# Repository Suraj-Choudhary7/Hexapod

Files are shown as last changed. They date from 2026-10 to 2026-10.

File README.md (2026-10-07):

# Hexapod Robot — ROS 2 / Gazebo Fortress

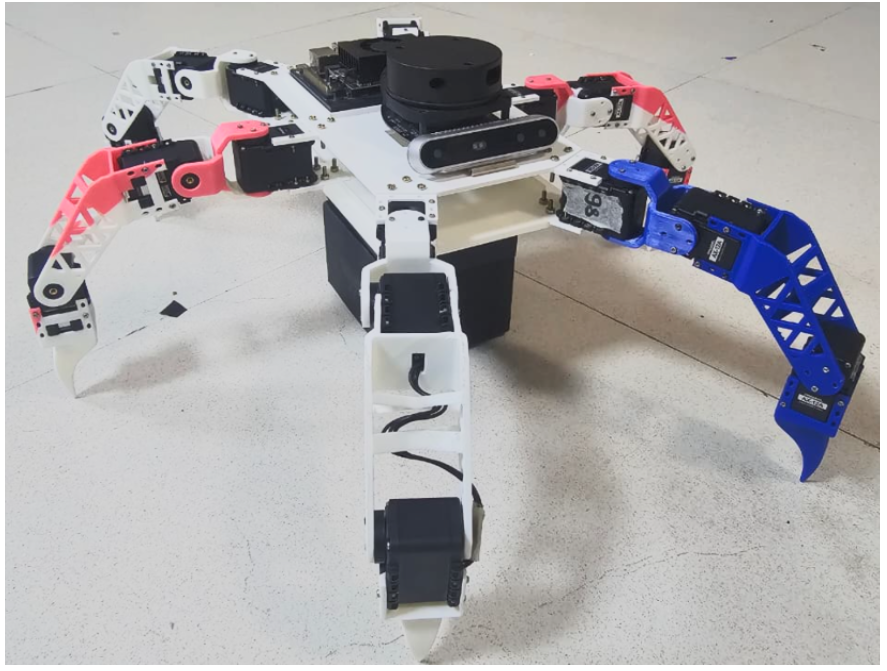
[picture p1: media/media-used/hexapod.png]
HexaPod


A 6-legged (hexapod) robot built from scratch: custom 3D-printed links, Dynamixel AX-series servos, a hand-derived URDF, and a fully original CPG-based walking controller written in Python on ROS 2 Humble.

<!-- Add a photo or GIF of the robot here -->
<!-- ![Robot photo](docs/images/robot.jpg) -->

---

## Table of Contents

- [What I Built & Learned](#what-i-built--learned)
- [Repository Structure](#repository-structure)
- [System Architecture](#system-architecture)
- [Package Details](#package-details)
  - [hexa\_control](#hexa_control)
  - [root\_description](#root_description)
- [Robot Specifications](#robot-specifications)
- [Getting Started](#getting-started)
  - [Prerequisites](#prerequisites)
  - [Build](#build)
  - [Run in Simulation (Gazebo Fortress)](#run-in-simulation-gazebo-fortress)
  - [Run on Hardware](#run-on-hardware)
  - [URDF Viewer (RViz only)](#urdf-viewer-rviz-only)
- [Controlling the Robot](#controlling-the-robot)
- [Screenshots & Videos](#screenshots--videos)
- [Roadmap](#roadmap)

---

## What I Built & Learned

This project started from zero — no existing codebase, no pre-made libraries for the walking controller. Here is what I worked through end-to-end:

**Mechanical & URDF**
- Designed 6 identical leg assemblies, each with 3 revolute joints (coxa → femur → tibia), and assembled them symmetrically around a hexagonal base body.
- Wrote the entire URDF by hand as a modular xacro file, including inertial tensors, STL mesh references (scaled from mm to m), and ros2\_control hardware interfaces.
- Tuned joint limits to ±120° (2.094 rad), damping, and friction to match the physical Dynamixel AX behaviour.

**3-DOF Inverse & Forward Kinematics**
- Derived the analytical IK for the leg: coxa rotation (θ₁) from `atan2(y, x)`, then a 2-link planar IK in the vertical plane for femur (θ₂) and tibia (θ₃) using the law of cosines.
- Implemented zero-angle compensation (`femur_zero_angle = -35°`, `tibia_zero_angle = -60°`) to map from geometric angles to servo-relative angles.
- Also implemented forward kinematics for verification.

**CPG Gait Generator**
- Implemented a **Central Pattern Generator (CPG)** based on **Hopf oscillators** — the same class of bio-inspired controllers used in real legged-robot research.
- Each leg has its own oscillator; a **phase-bias coupling matrix** locks Tripod A (`FH_LH`, `MH_RH`, `BH_LH`) and Tripod B (`FH_RH`, `MH_LH`, `BH_RH`) 180° out of phase, producing a stable tripod gait automatically.
- The system of ODEs is integrated at 50 Hz using **4th-order Runge-Kutta (RK4)** for numerical stability.
- Stance and swing phases use separate angular velocities (controlled by `duty_factor = 0.70`) so stance is slower and swing is faster, like a real walking leg.
- Foot trajectories blend a planar ground-contact sweep with a raised swing arc, and the swing height is shaped by `sin^0.8` for a smooth, rounded step.

**ROS 2 Control Node**
- Built a full ROS 2 lifecycle-style node (`hexa_node`) with a clean **state machine**: `RESTING → TRANSITIONING → WALKING → TRANSITIONING → RESTING`.
- The robot auto-stands when a `/cmd_vel` command arrives, walks while commands are active, and gracefully returns to a folded rest pose after 5 s of idling.
- All state transitions interpolate joint angles smoothly over a configurable `transition_duration` so nothing snaps or jerks.
- On `Ctrl+C` / shutdown, `destroy_node()` drives the robot back to rest synchronously before closing, protecting the hardware.

**Dynamixel Hardware Driver**

- Wrote a low-level ROS 2 node that subscribes to the same `JointTrajectory` topic and drives 18 Dynamixel AX servos via **GroupSyncWrite** — one USB packet per control cycle instead of 18 individual writes, keeping latency low.
- Implemented the angle → raw-value conversion with per-joint direction and zero-offset correction so the same IK angles work identically on both hardware and simulation.

**Simulation Bridge**
- Because Gazebo joint directions differ from physical servo directions, I wrote a lightweight `sim_relay` node that intercepts the trajectory, applies per-joint direction and offset corrections, and republis`hes — keeping `hexa_node` hardware-agnostic.

**Gazebo Fortress Integration**
- Integrated `gz_ros2_control` so the simulated robot is driven by the same `JointTrajectoryController` as the real one.
- Set up `ros_gz_bridge` for `/clock`, `/tf`, and `/odom` bridging.
- Tuned the controller YAML for **open-loop mode** — necessary because `hexa_node` streams 1-point trajectories at 50 Hz and closed-loop would keep aborting goals mid-execution.

---

## Repository Structure

```
Hexapod/
├── hexa_control/          # ROS 2 Python package — walking controller + hardware driver
│   ├── hexa_control/
│   │   ├── hexa_node.py            # Main control node (CPG + IK + state machine)
│   │   ├── gait.py                 # CPG Hopf oscillator gait generator
│   │   ├── kinematics.py           # Analytical 3-DOF IK / FK
│   │   ├── dynamixels_controller.py# Dynamixel AX hardware driver node
│   │   └── sim_relay.py            # Simulation direction-correction bridge
│   ├── setup.py
│   └── package.xml
│
└── root_description/      # ROS 2 CMake package — URDF, meshes, launch, config
    ├── urdf/
    │   ├── root.xacro              # Main robot URDF (all links & joints)
    │   ├── root.ros2_control.xacro # ros2_control hardware interface
    │   ├── root.gazebo.xacro       # Gazebo-specific plugins
    │   └── materials.xacro         # Visual materials
    ├── meshes/                     # STL files for all robot links
    ├── launch/
    │   ├── gz_sim.launch.py        # Full Gazebo Fortress + controller + hexa_node
    │   └── display.launch.py       # RViz + joint_state_publisher_gui (no sim)
    ├── config/
    │   └── controllers.yaml        # ros2_control controller config (100 Hz)
    ├── worlds/
    │   └── hexapod_world.sdf       # Custom Gazebo world
    └── rviz/
        └── root.rviz               # RViz configuration
```

---

## System Architecture

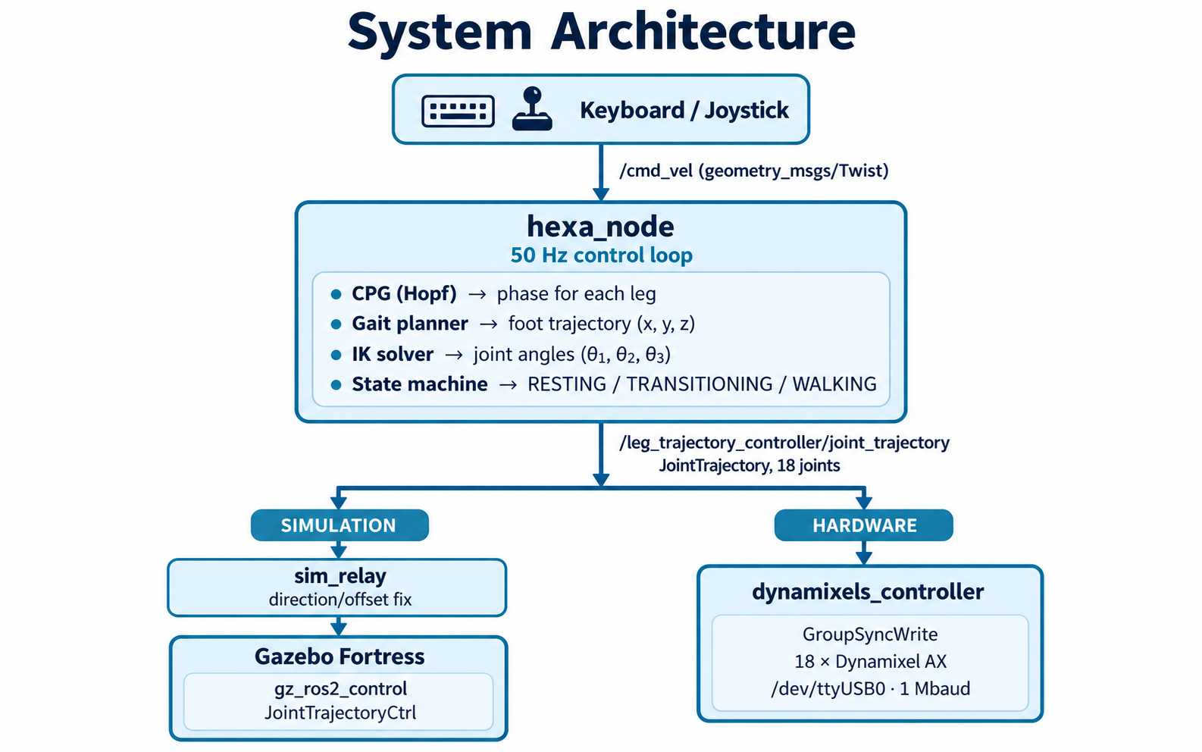
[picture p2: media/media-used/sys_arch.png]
System Architecture


---

## Package Details

### hexa_control

| File | Purpose |
|---|---|
| `hexa_node.py` | Main ROS 2 node. 50 Hz timer, state machine, integrates CPG + IK, publishes `JointTrajectory`. |
| `gait.py` | `CpgGait` class. Hopf oscillator per leg, RK4 integration, tripod phase coupling, foot trajectory. |
| `kinematics.py` | `Kinematics` class. Analytical IK (`theta1`, `theta2`, `theta3`) and FK. |
| `dynamixels_controller.py` | `DynamixelDriverNode`. Subscribes to `JointTrajectory`, converts angles to raw Dynamixel positions, SyncWrite at 1 Mbaud. |
| `sim_relay.py` | `SimRelayNode`. Translates `hexa_node` output to simulator joint conventions (direction flip + offsets). |

**ROS 2 entry points (from `setup.py`):**

```
hexa_node          → hexa_control.hexa_node:main
dynamixels_driver  → hexa_control.dynamixels_controller:main
sim_relay          → hexa_control.sim_relay:main
```

**Key parameters (hexa_node):**

| Parameter | Default | Description |
|---|---|---|
| `control_rate_hz` | `50.0` | Control loop frequency |
| `gait_frequency` | `0.5` | CPG oscillation frequency (Hz) |
| `step_height` | `0.06` | Swing phase foot lift (m) |
| `stance_reach_x` | `0.160` | Default foot forward reach (m) |
| `standing_height` | `-0.190` | Body height above ground (m) |
| `transition_duration_sec` | `1.5` | Sit/stand interpolation time (s) |
| `idle_to_rest_sec` | `5.0` | Idle timeout before sitting (s) |

---

### root_description

| File/Dir | Purpose |
|---|---|
| `urdf/root.xacro` | Full robot URDF: `base_link`, 6 Dynamixel mounts, 6 × 3 leg links, all joints |
| `urdf/root.ros2_control.xacro` | Hardware interface declaration for `gz_ros2_control` |
| `urdf/root.gazebo.xacro` | Gazebo Fortress plugin (`gz_ros2_control`) |
| `config/controllers.yaml` | `JointTrajectoryController` for 18 joints, 100 Hz, open-loop |
| `launch/gz_sim.launch.py` | Full sim launch: Gazebo + RSP + spawn + bridge + controllers + hexa_node + sim_relay |
| `launch/display.launch.py` | URDF viewer: RSP + joint_state_publisher_gui + RViz |
| `meshes/` | STL meshes for base, Dynamixel brackets, femur, tibia links |
| `worlds/hexapod_world.sdf` | Flat-ground Gazebo world |

---

## Robot Specifications

| Property | Value |
|---|---|
| Legs | 6 (hexapod) |
| DOF per leg | 3 (coxa, femur, tibia) |
| Total joints | 18 |
| Actuators | Dynamixel AX series (protocol 1.0) |
| Coxa length (l1) | 51 mm |
| Femur length (l2) | 110 mm |
| Tibia length (l3) | 148 mm |
| Body mass (URDF) | ~0.90 kg |
| Gait type | Tripod (CPG Hopf oscillator) |
| Control frequency | 50 Hz |
| Communication | USB-to-TTL @ 1 Mbaud |

**Leg naming convention:**

```
FH = Front Hex   MH = Middle Hex   BH = Back Hex
LH = Left Half   RH = Right Half

      FH_LH ── FH_RH
     /               \
   MH_LH           MH_RH
     \               /
      BH_LH ── BH_RH
```

**Tripod groups:**
- **Tripod A** (swing together): `FH_LH`, `MH_RH`, `BH_LH`
- **Tripod B** (swing together): `FH_RH`, `MH_LH`, `BH_RH`

---

## Getting Started

### Prerequisites

- **ROS 2 Humble** (Ubuntu 22.04)
- **Gazebo Fortress** with `ros_gz_sim`, `ros_gz_bridge`, `gz_ros2_control`
- **ros2_control** stack: `controller_manager`, `joint_state_broadcaster`, `joint_trajectory_controller`
- Python: `numpy` (for gait CPG) , `rclpy`
- Hardware only: `dynamixel_sdk` Python package

```bash
# ROS 2 Humble + Gazebo Fortress meta-packages
sudo apt install ros-humble-ros-gz ros-humble-gz-ros2-control \
     ros-humble-ros2-control ros-humble-ros2-controllers \
     ros-humble-xacro ros-humble-joint-state-publisher-gui

# Python deps
pip install numpy dynamixel-sdk
```

### Build

```bash
cd ~/hexa_ws          # or wherever you cloned this
colcon build --symlink-install
source install/setup.bash
```

### Run in Simulation (Gazebo Fortress)

```bash
source install/setup.bash
ros2 launch root_description gz_sim.launch.py
OR 
bash /home/suraj/hexa_ws/run_sim.sh
```

This starts: Gazebo Fortress → spawns the robot → loads ros2_control controllers → starts `hexa_node` + `sim_relay`.
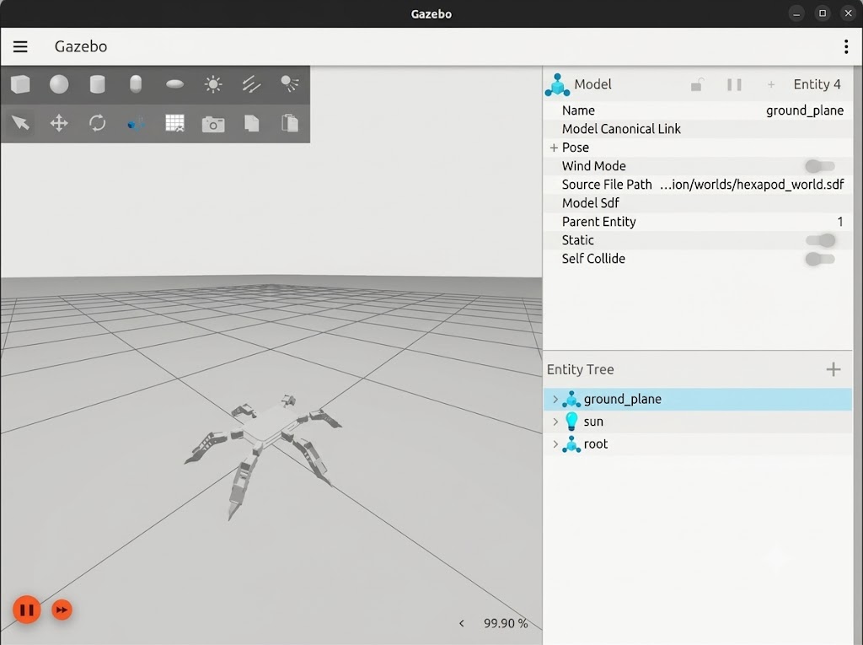
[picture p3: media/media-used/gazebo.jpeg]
Gazebo

Send velocity commands to make it walk:

```bash
# Forward
ros2 topic pub --once /cmd_vel geometry_msgs/msg/Twist \
  "{linear: {x: 0.05, y: 0.0, z: 0.0}, angular: {z: 0.0}}"

# Turn in place
ros2 topic pub --once /cmd_vel geometry_msgs/msg/Twist \
  "{linear: {x: 0.0, y: 0.0, z: 0.0}, angular: {z: 0.3}}"

# Stop (robot will auto-sit after 5 s)
ros2 topic pub --once /cmd_vel geometry_msgs/msg/Twist \
  "{linear: {x: 0.0}, angular: {z: 0.0}}"
```

### Run on Hardware

Connect the Dynamixel U2D2 (or USB-to-TTL adapter) and run:

```bash
source install/setup.bash

# Terminal 1 — main controller
ros2 run hexa_control hexa_node

# Terminal 2 — hardware driver
ros2 run hexa_control dynamixels_driver \
  --ros-args -p device:=/dev/ttyUSB0 -p baudrate:=1000000

# Terminal 3 - control method
source ~/hexa_ws/install/setup.bash
ros2 run teleop_twist_keyboard teleop_twist_keyboard    #For keyboard teleop
                OR
ros2 run teleop_twist_joy teleop_node --ros-args -p scale_linear.x:=0.05 -p scale_angular.z:=0.05   #For controller teleop
ros2 run joy joy_node
```

> Make sure your user is in the `dialout` group: `sudo usermod -aG dialout $USER`

### URDF Viewer (RViz only)
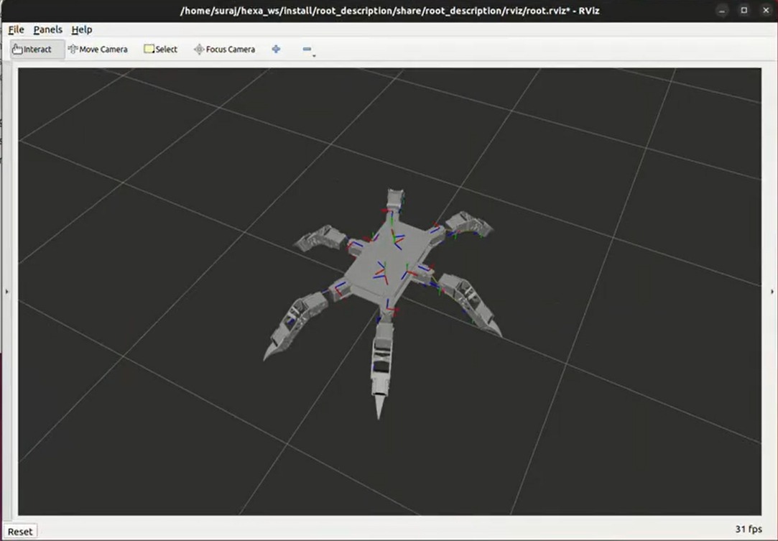
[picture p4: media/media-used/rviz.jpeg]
Rviz2

```bash
ros2 launch root_description display.launch.py
```

Drag the sliders in `joint_state_publisher_gui` to manually pose each leg.

---

## Controlling the Robot

The robot reacts to `geometry_msgs/Twist` on `/cmd_vel`:

| Field | Effect |
|---|---|
| `linear.x` | Forward / backward walking |
| `linear.y` | Strafing left / right |
| `angular.z` | Turning / rotating in place |

You can also use `teleop_twist_keyboard`:

```bash
ros2 run teleop_twist_keyboard teleop_twist_keyboard
```
or else use `teleop_twist_joy`:

```bash
ros2 run teleop_twist_joy teleop_node --ros-args -p scale_linear.x:=0.05 -p scale_angular.z:=0.05
ros2 run joy joy_node
```
---

## Screenshots & Videos

<!-- Add your screenshots and videos here once you have them -->
### Gazebo Fortress simulation
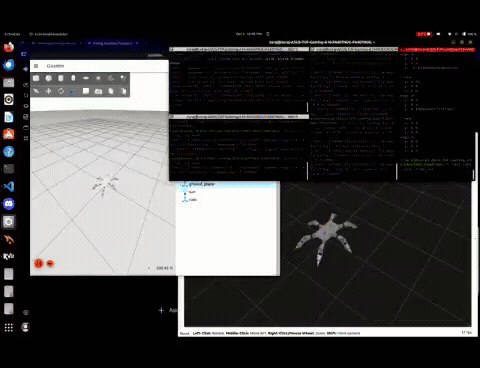
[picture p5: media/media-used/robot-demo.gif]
Simulation

### Physical robot
Hardware

---

## Future Roadmap

- [ ] IMU-based body levelling
- [ ] Terrain-adaptive foot force estimation
- [ ] Navigation stack integration (Nav2 + LiDAR)
- [ ] Faster gait modes (wave, ripple)
- [ ] GUI parameter tuner for CPG gains

## PROJECT MEMBERS

- [**SURAJ CHOUDHARY**](https://github.com/Suraj-Choudhary7)
- [**DARSHAN PANCHAL**](https://github.com/Darshan-387)
- [**MOHAMMAD AFFAN HAIDER**](https://github.com/ThatOneNewbGUY)

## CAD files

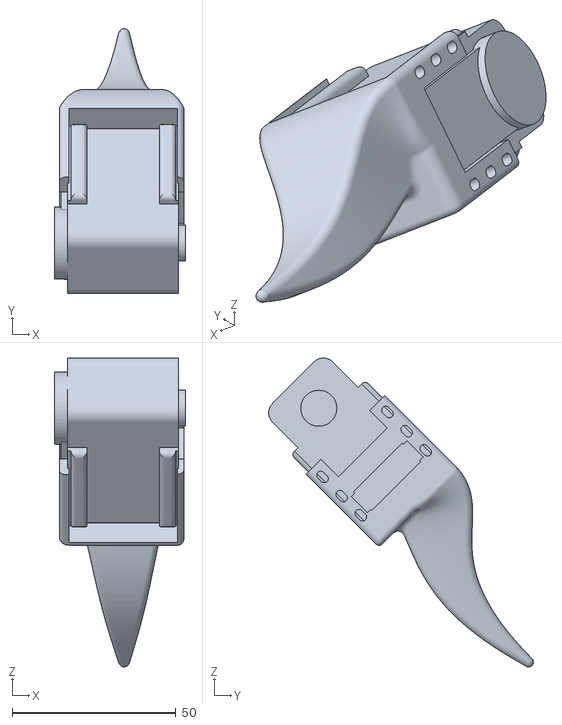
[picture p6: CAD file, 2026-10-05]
root_description/meshes/link_3.stl
40.0 x 80.8 x 94.2

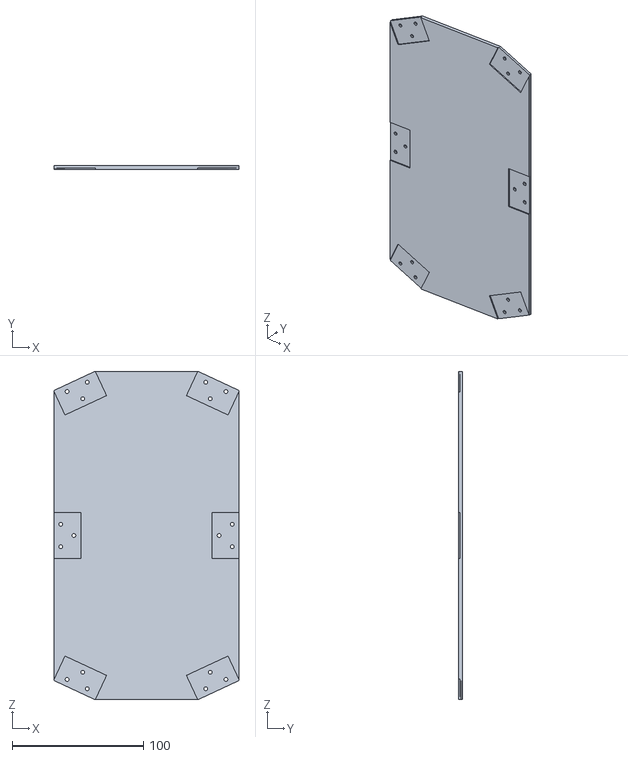
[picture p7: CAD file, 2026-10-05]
root_description/meshes/top_plate.stl
140.7 x 3.00 x 250.0

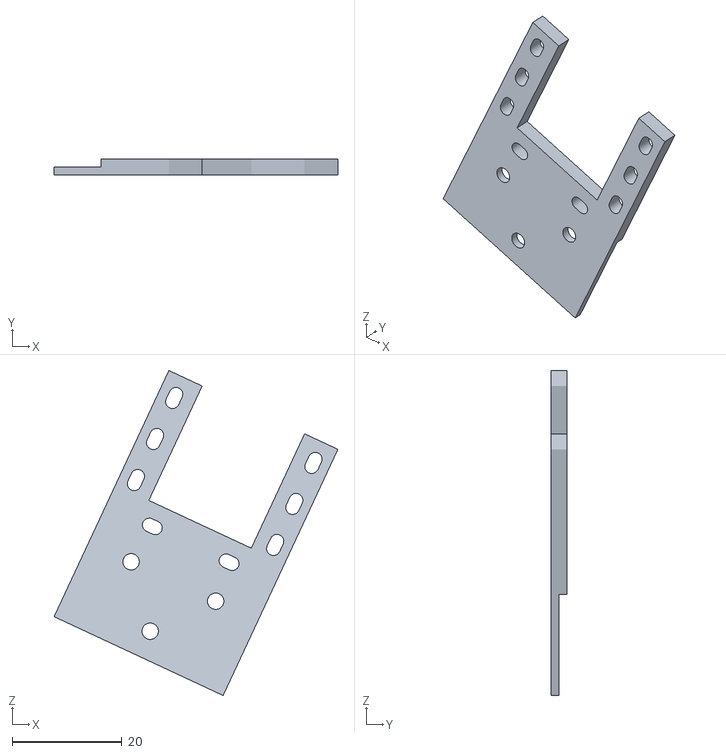
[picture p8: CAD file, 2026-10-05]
root_description/meshes/Dynamaxial_cover_top.stl
51.7 x 3.00 x 59.2

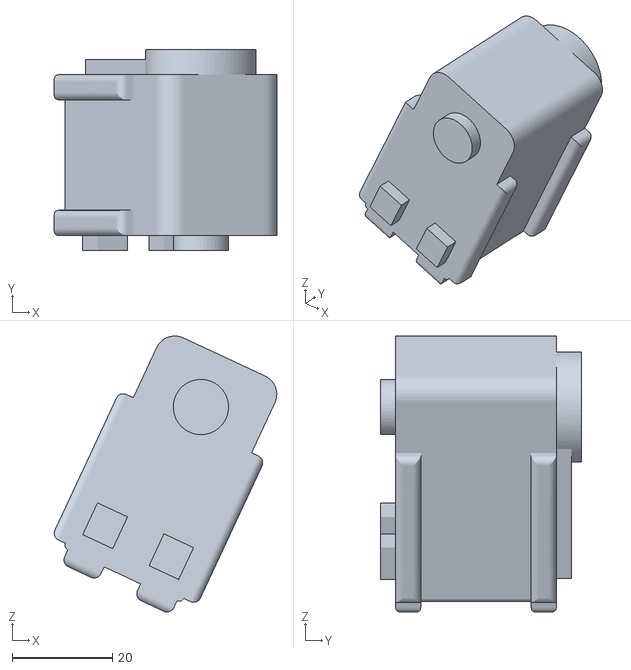
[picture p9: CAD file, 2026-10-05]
root_description/meshes/Dynamaxial.stl
44.3 x 40.0 x 55.0

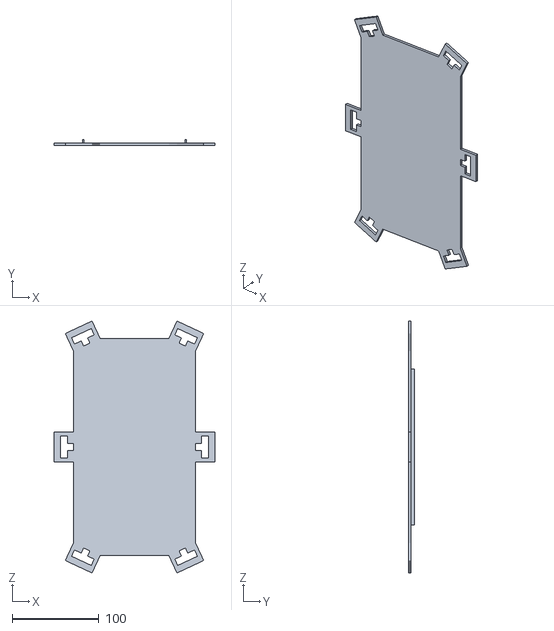
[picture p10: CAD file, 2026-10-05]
root_description/meshes/base_link.stl
184.7 x 7.00 x 289.9

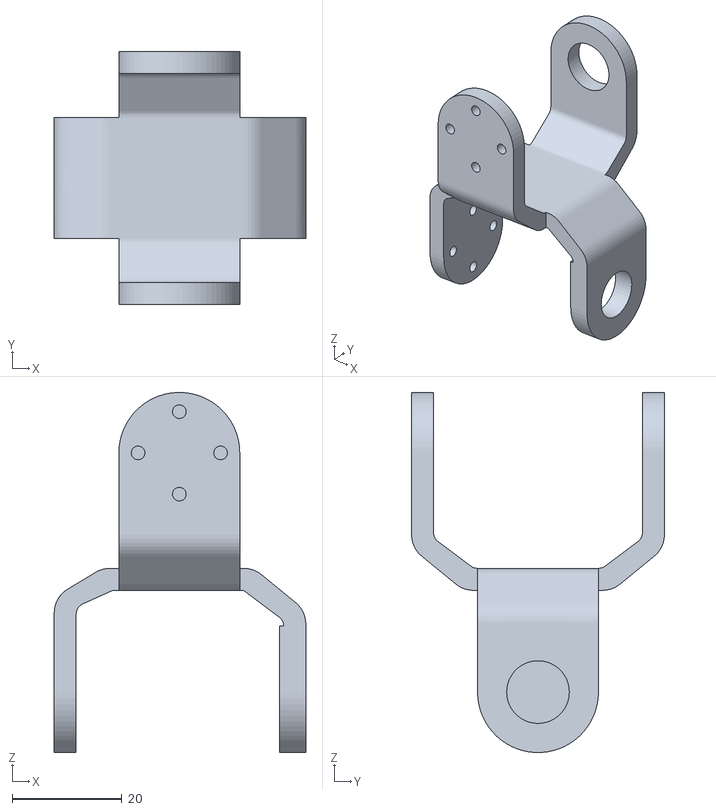
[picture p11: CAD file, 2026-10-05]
root_description/meshes/link_1.stl
45.8 x 46.0 x 65.5

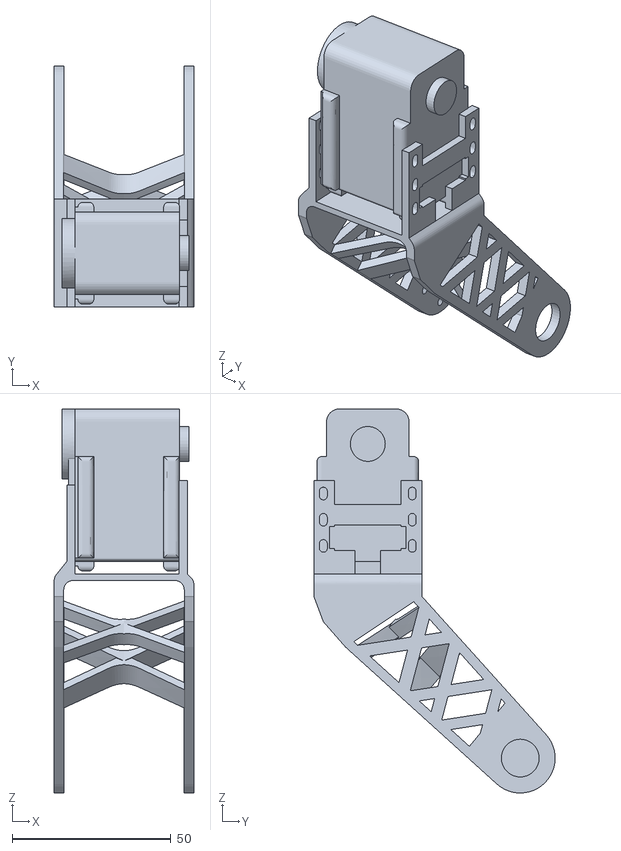
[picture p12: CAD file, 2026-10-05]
root_description/meshes/link_2.stl
44.0 x 76.0 x 120.9

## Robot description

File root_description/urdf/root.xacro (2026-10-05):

<?xml version="1.0" ?>
<robot name="root" xmlns:xacro="http://www.ros.org/wiki/xacro">

<xacro:include filename="$(find root_description)/urdf/materials.xacro" />
<xacro:include filename="$(find root_description)/urdf/root.ros2_control.xacro" />
<xacro:include filename="$(find root_description)/urdf/root.gazebo.xacro" />
<link name="base_link">
  <inertial>
    <origin xyz="9.140424259375743e-15 0.0015878993733457899 7.514578729508475e-15" rpy="0 0 1"/>
    <mass value="0.9002111959231273"/>
    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
  </inertial>
  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
</link>

<link name="Dynamaxial_1">
  <inertial>
    <origin xyz="0.008972645350292519 0.02009922137903257 0.009778378451293368" rpy="0 0 0"/>
    <mass value="0.3595998121158479"/>
    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
  </inertial>
  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
</link>

<link name="Dynamaxial_2">
  <inertial>
    <origin xyz="0.008972645350292519 0.02009922137903257 0.009778378451293368" rpy="0 0 0"/>
    <mass value="0.3595998121158479"/>
    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
  </inertial>
  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
</link>


<link name="Dynamaxial_3">
  <inertial>
    <origin xyz="0.008972645350292519 0.02009922137903257 0.009778378451293368" rpy="0 0 0"/>
    <mass value="0.3595998121158479"/>
    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
  </inertial>
  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
</link>

<link name="Dynamaxial_4">
  <inertial>
    <origin xyz="0.008972645350292519 0.02009922137903257 0.009778378451293368" rpy="0 0 0"/>
    <mass value="0.3595998121158479"/>
    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
  </inertial>
  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
</link>

<link name="Dynamaxial_5">
  <inertial>
    <origin xyz="0.008972645350292519 0.02009922137903257 0.009778378451293368" rpy="0 0 0"/>
    <mass value="0.3595998121158479"/>
    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
  </inertial>
  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
</link>


<link name="Dynamaxial_6">
  <inertial>
    <origin xyz="0.008972645350292519 0.02009922137903257 0.009778378451293368" rpy="0 0 0"/>
    <mass value="0.3595998121158479"/>
    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
  </inertial>
  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
</link>


<link name="Dynamaxial_top_plate_1">
  <inertial>
    <origin xyz="-0.04860069324280111 0.0005424823737990442 -0.1042254181604586" rpy="0 0 0"/>
    <mass value="0.7717368116814207"/>
    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
  </inertial>
  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
</link>

<link name="connect_top_plate_1">
  <inertial>
    <origin xyz="-0.0055922169544652955 -0.0048193928964247665 0.09582519093081569" rpy="0 0 0"/>
    <mass value="0.018497767072455207"/>
    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
  </inertial>
  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
</link>

<link name="connect_top_plate_2">
  <inertial>
    <origin xyz="-0.0055922169544652955 -0.0048193928964247665 0.09582519093081569" rpy="0 0 0"/>
    <mass value="0.018497767072455207"/>
    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
  </inertial>
  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
</link>

<link name="connect_top_plate_3">
  <inertial>
    <origin xyz="-0.0055922169544652955 -0.0048193928964247665 0.09582519093081569" rpy="0 0 0"/>
    <mass value="0.018497767072455207"/>
    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
  </inertial>
  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
</link>

<link name="connect_top_plate_4">
  <inertial>
    <origin xyz="-0.0055922169544652955 -0.0048193928964247665 0.09582519093081569" rpy="0 0 0"/>
    <mass value="0.018497767072455207"/>
    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
  </inertial>
  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
</link>

<link name="connect_top_plate_5">
  <inertial>
    <origin xyz="-0.0055922169544652955 -0.0048193928964247665 0.09582519093081569" rpy="0 0 0"/>
    <mass value="0.018497767072455207"/>
    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
  </inertial>
  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
</link>

<link name="connect_top_plate_6">
  <inertial>
    <origin xyz="-0.0055922169544652955 -0.0048193928964247665 0.09582519093081569" rpy="0 0 0"/>
    <mass value="0.018497767072455207"/>
    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
  </inertial>
  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
</link>

<joint name="Joint1" type="fixed">
  <origin xyz="0.057062 0.0 0.13401" rpy="0 -0.01 0"/>
  <parent link="base_link"/>
  <child link="Dynamaxial_1"/>
</joint>

<joint name="Joint2" type="fixed">
  <origin xyz="0.085 0.0 0.0055" rpy="0 1.13 0"/>
  <parent link="base_link"/>
  <child link="Dynamaxial_2"/>
</joint>

<joint name="Joint3" type="fixed">
  <origin xyz="0.06462 0.0 -0.130201" rpy="0 2.27 0"/>
  <parent link="base_link"/>
  <child link="Dynamaxial_3"/>
</joint>

<joint name="Joint4" type="fixed">
  <origin xyz="-0.057462 0.0 -0.133201" rpy="0 3.14 0"/>
  <parent link="base_link"/>
  <child link="Dynamaxial_4"/>
</joint>

<joint name="Joint5" type="fixed">
  <origin xyz="-0.085 0.0 -0.00370" rpy="0 -2.01 0"/>
  <parent link="base_link"/>
  <child link="Dynamaxial_5"/>
</joint>

<joint name="Joint6" type="fixed">
  <origin xyz="-0.065062 0.0 0.128401" rpy="0 -0.9 0"/>
  <parent link="base_link"/>
  <child link="Dynamaxial_6"/>
</joint>

<joint name="Joint7" type="fixed">
  <origin xyz="-0.013021 -0.0045 0.079895" rpy="0 0 0"/>
  <parent link="connect_top_plate_1"/>
  <child link="Dynamaxial_top_plate_1"/>
</joint>

<joint name="Joint8" type="fixed">
  <origin xyz="0.004692 0.041 -0.107457" rpy="0 0 0"/>
  <parent link="Dynamaxial_1"/>
  <child link="connect_top_plate_1"/>
</joint>

<joint name="Joint9" type="fixed">
  <origin xyz="0.004692 0.041 -0.107457" rpy="0 0 0"/>
  <parent link="Dynamaxial_2"/>
  <child link="connect_top_plate_2"/>
</joint>

<joint name="Joint10" type="fixed">
  <origin xyz="0.004692 0.041 -0.107457" rpy="0 0 0"/>
  <parent link="Dynamaxial_3"/>
  <child link="connect_top_plate_3"/>
</joint>

<joint name="Joint11" type="fixed">
  <origin xyz="0.004692 0.041 -0.107457" rpy="0 0 0"/>
  <parent link="Dynamaxial_4"/>
  <child link="connect_top_plate_4"/>
</joint>

<joint name="Joint12" type="fixed">
  <origin xyz="0.004692 0.041 -0.107457" rpy="0 0 0"/>
  <parent link="Dynamaxial_5"/>
  <child link="connect_top_plate_5"/>
</joint>

<joint name="Joint13" type="fixed">
  <origin xyz="0.004692 0.041 -0.107457" rpy="0 0 0"/>
  <parent link="Dynamaxial_6"/>
  <child link="connect_top_plate_6"/>
</joint>

<link name="link_FH_LH_2">
  <inertial>
    <origin xyz="0.019526961928152647 0.0040896573040327365 -0.027062240930987157" rpy="0 0 0"/>
    <mass value="0.5073894324425476"/>
    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
  </inertial>
  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
</link>

<link name="link_FH_LH_3">
  <inertial>
    <origin xyz="0.02019070727155603 0.017663951482134593 -0.01793253231179917" rpy="0 0 0"/>
    <mass value="0.532133797474928"/>
    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
  </inertial>
  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
</link>

<link name="link_FH_LH_1">
  <inertial>
    <origin xyz="-0.00021785660387237116 0.018447696948459432 -0.022506406667710283" rpy="0 0 0"/>
    <mass value="0.10934456227744341"/>
    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
  </inertial>
  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
</link>

<joint name="FH_LH_1" type="revolute">
  <origin xyz="0.015 0.04 0.02" rpy="3.14 0.384 0"/>
  <parent link="Dynamaxial_1"/>
  <child link="link_FH_LH_1"/>
  <axis xyz="0.0 1.0 0.0"/>
  <limit upper="2.094395" lower="-2.094395" effort="100" velocity="100"/>
  <dynamics damping="0.3" friction="0.05"/>
</joint>

<joint name="FH_LH_2" type="revolute">
  <origin xyz="-0.01875 0.019 -0.0435" rpy="0 0 0"/>
  <parent link="link_FH_LH_1"/>
  <child link="link_FH_LH_2"/>
  <axis xyz="1.0 0.0 0.0"/>
  <limit upper="2.094395" lower="-2.094395" effort="100" velocity="100"/>
  <dynamics damping="0.3" friction="0.05"/>
</joint>

<joint name="FH_LH_3" type="revolute">
  <origin xyz="0.0006 0.048009 -0.098942" rpy="0 0 0"/>
  <parent link="link_FH_LH_2"/>
  <child link="link_FH_LH_3"/>
  <axis xyz="1.0 0.0 0.0"/>
  <limit upper="2.094395" lower="-2.094395" effort="100" velocity="100"/>
  <dynamics damping="0.3" friction="0.05"/>
</joint>

<link name="link_FH_RH_2">
  <inertial>
    <origin xyz="0.019526961928152647 0.0040896573040327365 -0.027062240930987157" rpy="0 0 0"/>
    <mass value="0.5073894324425476"/>
    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
  </inertial>
  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
</link>

<link name="link_FH_RH_3">
  <inertial>
    <origin xyz="0.02019070727155603 0.017663951482134593 -0.01793253231179917" rpy="0 0 0"/>
    <mass value="0.532133797474928"/>
    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
  </inertial>
  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
</link>

<link name="link_FH_RH_1">
  <inertial>
    <origin xyz="-0.00021785660387237116 0.018447696948459432 -0.022506406667710283" rpy="0 0 0"/>
    <mass value="0.10934456227744341"/>
    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
  </inertial>
  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
</link>

<joint name="FH_RH_1" type="revolute">
  <origin xyz="0.015 0.04 0.02" rpy="3.14 0.384 0"/>
  <parent link="Dynamaxial_6"/>
  <child link="link_FH_RH_1"/>
  <axis xyz="0.0 1.0 0.0"/>
  <limit upper="2.094395" lower="-2.094395" effort="100" velocity="100"/>
  <dynamics damping="0.3" friction="0.05"/>
</joint>
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

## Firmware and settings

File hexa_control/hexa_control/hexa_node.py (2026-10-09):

#!/usr/bin/env python3
import math
import time
import rclpy
from rclpy.node import Node
from geometry_msgs.msg import Twist
from trajectory_msgs.msg import JointTrajectory, JointTrajectoryPoint
from builtin_interfaces.msg import Duration
from hexa_control.kinematics import Kinematics
from hexa_control.gait import CpgGait


class HexapodControllerNode(Node):
    def __init__(self):
        super().__init__('hexa_node')

        self.declare_parameter('control_rate_hz', 50.0)
        self.declare_parameter('gait_frequency', 0.5)
        self.declare_parameter('step_height', 0.06)
        self.declare_parameter('stance_reach_x', 0.160)
        self.declare_parameter('standing_height', -0.190)
        self.declare_parameter('transition_duration_sec', 1.5)
        self.declare_parameter('idle_to_rest_sec', 5.0)

        rate_hz = self.get_parameter('control_rate_hz').value
        gait_freq = self.get_parameter('gait_frequency').value
        step_h = self.get_parameter('step_height').value
        stance_x = self.get_parameter('stance_reach_x').value
        stand_z = self.get_parameter('standing_height').value
        self.transition_duration = self.get_parameter('transition_duration_sec').value
        self.idle_to_rest_sec = self.get_parameter('idle_to_rest_sec').value
        self.dt = 1.0 / rate_hz

        self.kinematics = Kinematics(l1=0.051, l2=0.110, l3=0.148)
        self.gait = CpgGait(frequency=gait_freq, amplitude=step_h, normal_x=stance_x, normal_z=stand_z)

        self.joint_names = [
            'FH_LH_1', 'FH_LH_2', 'FH_LH_3',
            'FH_RH_1', 'FH_RH_2', 'FH_RH_3',
            'MH_LH_1', 'MH_LH_2', 'MH_LH_3',
            'MH_RH_1', 'MH_RH_2', 'MH_RH_3',
            'BH_RH_1', 'BH_RH_2', 'BH_RH_3',
            'BH_LH_1', 'BH_LH_2', 'BH_LH_3'
        ]
        self.legs = ['FH_LH', 'FH_RH', 'MH_LH', 'MH_RH', 'BH_RH', 'BH_LH']

        # ---- Rest / Stand joint-angle poses (radians) ----
        # STAND_POSE: neutral standing reach, derived from the gait's own
        # normal_x/normal_z via IK — consistent with what the gait already
        # treats as "center" at phase 0.
        stand_angles = self.kinematics.inverse_kinematics(stance_x, 0.0, stand_z)
        self.STAND_POSE = {}
        for leg in self.legs:
            for i, ang in enumerate(stand_angles, start=1):
                self.STAND_POSE[f'{leg}_{i}'] = ang

        # REST_POSE: legs tucked inward (x=0.09) but feet at the same height
        # as the stand pose (z=stand_z).  Keeping z the same as standing means
        # the feet stay on the ground in both poses — the robot is always
        # supported.  The standup transition then only moves feet *outward*
        # (x: 0.09 -> stance_x), with no vertical component, so the body
        # never collapses during REST -> STAND.
        rest_angles = self.kinematics.inverse_kinematics(0.09, 0.0, stand_z)
        self.REST_POSE = {}
        for leg in self.legs:
            for i, ang in enumerate(rest_angles, start=1):
                self.REST_POSE[f'{leg}_{i}'] = ang

        # ---- FSM state ----
        # 'RESTING', 'TRANSITIONING', 'STANDING', 'WALKING'
        self.state = 'RESTING'
        self.current_angles = dict(self.REST_POSE)   # last angles actually published

        # Non-blocking transition bookkeeping
        self._transition_start_pose = None   # snapshot of angles at transition begin
        self._transition_target = None
        self._transition_steps_total = 0
        self._transition_step_count = 0
        self._post_transition_state = None  # state to enter once transition finishes

        self.cmd_vx = 0.0
        self.cmd_vy = 0.0
        self.cmd_wz = 0.0

        # Idle timer: counts seconds of continuous zero velocity while STANDING.
        # When it exceeds idle_to_rest_sec the robot sits back down to REST.
        self._idle_time = 0.0

        self.cmd_sub = self.create_subscription(Twist, '/cmd_vel', self.cmd_vel_callback, 10)
        self.traj_pub = self.create_publisher(
            JointTrajectory, '/leg_trajectory_controller/joint_trajectory', 10
        )

        self.timer = self.create_timer(self.dt, self.control_loop)

        self.get_logger().info('Hexapod CPG Controller started (RESTING).')

    def cmd_vel_callback(self, msg: Twist):
        self.cmd_vx = msg.linear.x
        self.cmd_vy = msg.linear.y
        self.cmd_wz = msg.angular.z

    def _publish_angles(self, angles_dict):
        traj_msg = JointTrajectory()
        traj_msg.header.stamp = self.get_clock().now().to_msg()
        traj_msg.joint_names = self.joint_names

        point = JointTrajectoryPoint()
        point.positions = [angles_dict[name] for name in self.joint_names]
        point.time_from_start = Duration(sec=0, nanosec=int(self.dt * 1e9))
        traj_msg.points.append(point)

        self.traj_pub.publish(traj_msg)
        self.current_angles = dict(angles_dict)

    def _start_transition(self, target_pose, post_state):
        """Begin a non-blocking interpolation from current_angles to target_pose."""
        self.state = 'TRANSITIONING'
        self._transition_start_pose = dict(self.current_angles)  # fixed snapshot
        self._transition_target = target_pose
        self._transition_steps_total = max(1, int(self.transition_duration / self.dt))
        self._transition_step_count = 0
        self._post_transition_state = post_state

    def _step_transition(self):
        """Advance one tick of an in-progress interpolation; publish the interpolated pose."""
        self._transition_step_count += 1
        alpha = self._transition_step_count / float(self._transition_steps_total)
        alpha = min(1.0, alpha)

        # Use the fixed start snapshot — not self.current_angles (which changes each tick)
        interp = {
            name: self._transition_start_pose[name]
                  + alpha * (self._transition_target[name] - self._transition_start_pose[name])
            for name in self.joint_names
        }
        self._publish_angles(interp)

        if alpha >= 1.0:
            self.state = self._post_transition_state
            self.get_logger().info(f'Transition complete -> {self.state}')

    def control_loop(self):
        is_moving = (abs(self.cmd_vx) > 0.01 or abs(self.cmd_vy) > 0.01 or abs(self.cmd_wz) > 0.01)

        # --- In the middle of a smooth transition: just advance it ---
        if self.state == 'TRANSITIONING':
            self._step_transition()
            return

        # --- Auto stand-up if movement commanded while resting ---
        if is_moving and self.state == 'RESTING':
            self.get_logger().info('Movement command received — auto standing up...')
            self._idle_time = 0.0
            self._start_transition(self.STAND_POSE, post_state='WALKING')
            return

        # --- Walking / Standing: run the gait + IK pipeline ---
        if is_moving or self.state == 'WALKING':
            self.state = 'WALKING' if is_moving else 'STANDING'

            if is_moving:
                # Reset idle timer whenever the robot is actually moving
                self._idle_time = 0.0
            else:
                # Velocity dropped to zero while we were WALKING -> now STANDING idle
                self._idle_time += self.dt
                if self._idle_time >= self.idle_to_rest_sec:
                    self.get_logger().info(
                        f'Idle for {self.idle_to_rest_sec:.0f}s — returning to REST...'
                    )
                    self._idle_time = 0.0
                    self._start_transition(self.REST_POSE, post_state='RESTING')
                    return

            vel_magnitude = math.sqrt(self.cmd_vx**2 + self.cmd_vy**2 + self.cmd_wz**2)
            self.gait.cpg_phase(self.dt, vel_magnitude)

            joint_positions_dict = {}
            for leg in self.legs:
                x, y, z = self.gait.foot_trajectory(leg, self.cmd_vx, self.cmd_vy, self.cmd_wz)
                q1, q2, q3 = self.kinematics.inverse_kinematics(x, y, z)
                joint_positions_dict[f'{leg}_1'] = q1
                joint_positions_dict[f'{leg}_2'] = q2
                joint_positions_dict[f'{leg}_3'] = q3

            self._publish_angles(joint_positions_dict)
            return

        # --- Otherwise: idle in current state (RESTING with v=0) ---
        # Nothing to publish — hold last commanded pose.

    def destroy_node(self):
        """On shutdown, synchronously move all legs to REST_POSE before closing."""
        self.get_logger().info('Shutdown requested — moving to REST pose...')

        # Cancel the control loop timer so it stops interfering
        self.timer.cancel()

        # Compute a blocking rest sequence: interpolate over transition_duration
        steps = max(1, int(self.transition_duration / self.dt))
        start_pose = dict(self.current_angles)

        for step in range(1, steps + 1):
            alpha = min(1.0, step / float(steps))
            interp = {
                name: start_pose[name]
                      + alpha * (self.REST_POSE[name] - start_pose[name])
                for name in self.joint_names
            }
            self._publish_angles(interp)
            time.sleep(self.dt)

        self.get_logger().info('REST pose reached — shutting down.')
        super().destroy_node()


def main(args=None):
    rclpy.init(args=args)
    node = HexapodControllerNode()
    try:
        rclpy.spin(node)
    except KeyboardInterrupt:
        pass
    finally:
        node.destroy_node()
        if rclpy.ok():
            rclpy.shutdown()


if __name__ == '__main__':
    main()

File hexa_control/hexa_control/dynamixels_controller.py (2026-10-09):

#!/usr/bin/env python3
import rclpy
from rclpy.node import Node
from trajectory_msgs.msg import JointTrajectory

from dynamixel_sdk import (
    PortHandler, PacketHandler, GroupSyncWrite,
    DXL_LOBYTE, DXL_HIBYTE, COMM_SUCCESS,
)

# AX-12A Control Table
ADDR_TORQUE_ENABLE = 24
ADDR_GOAL_POSITION = 30
LEN_GOAL_POSITION  = 2

PROTOCOL_VERSION   = 1.0

# Conversion: 1023 ticks over 300 degrees
RAD_TO_RAW = 1023.0 / (300.0 * 3.141592653589793 / 180.0)  # ≈ 195.38
CENTER_RAW = 512

# Physical neutral positions from your manual test:
#   coxa  → 512 raw  → offset = (512 - 512) / 195.38 = 0.000 rad
#   femur → 631 raw  → offset = (631 - 512) / 195.38 = 0.609 rad
#   tibia → 716 raw  → offset = (716 - 512) / 195.38 = 1.044 rad
COXA_OFFSET  =  0.000
FEMUR_OFFSET = -0.8264
TIBIA_OFFSET = -1.7349

# Joint config: maps ROS joint name → Dynamixel ID, offset, direction
# direction = -1 for right-side coxa joints (mirrored legs)
JOINT_CONFIG = {
    # Leg 1 — Front Left (FH_LH)
    'FH_LH_1': {'id': 11, 'offset': COXA_OFFSET,  'dir':  1},
    'FH_LH_2': {'id': 12, 'offset': FEMUR_OFFSET, 'dir': -1},
    'FH_LH_3': {'id': 13, 'offset': TIBIA_OFFSET, 'dir': -1},

    # Leg 2 — Front Right (FH_RH)
    'FH_RH_1': {'id': 61, 'offset': COXA_OFFSET,  'dir':  1},
    'FH_RH_2': {'id': 62, 'offset': FEMUR_OFFSET, 'dir': -1},
    'FH_RH_3': {'id': 63, 'offset': TIBIA_OFFSET, 'dir': -1},

    # Leg 3 — Middle Left (MH_LH)
    'MH_LH_1': {'id': 21, 'offset': COXA_OFFSET,  'dir':  1},
    'MH_LH_2': {'id': 22, 'offset': FEMUR_OFFSET, 'dir': -1},
    'MH_LH_3': {'id': 23, 'offset': TIBIA_OFFSET, 'dir': -1},

    # Leg 4 — Middle Right (MH_RH)
    'MH_RH_1': {'id': 51, 'offset': COXA_OFFSET,  'dir':  1},
    'MH_RH_2': {'id': 52, 'offset': FEMUR_OFFSET, 'dir': -1},
    'MH_RH_3': {'id': 53, 'offset': TIBIA_OFFSET, 'dir': -1},

    # Leg 5 — Back Right (BH_RH)
    'BH_RH_1': {'id': 41, 'offset': COXA_OFFSET,  'dir':  1},
    'BH_RH_2': {'id': 42, 'offset': FEMUR_OFFSET, 'dir': -1},
    'BH_RH_3': {'id': 43, 'offset': TIBIA_OFFSET, 'dir': -1},

    # Leg 6 — Back Left (BH_LH)
    'BH_LH_1': {'id': 31, 'offset': COXA_OFFSET,  'dir':  1},
    'BH_LH_2': {'id': 32, 'offset': FEMUR_OFFSET, 'dir': -1},
    'BH_LH_3': {'id': 33, 'offset': TIBIA_OFFSET, 'dir': -1},
}

# Same order as hexa_node's joint_names list
JOINT_ORDER = [
    'FH_LH_1', 'FH_LH_2', 'FH_LH_3',
    'FH_RH_1', 'FH_RH_2', 'FH_RH_3',
    'MH_LH_1', 'MH_LH_2', 'MH_LH_3',
    'MH_RH_1', 'MH_RH_2', 'MH_RH_3',
    'BH_RH_1', 'BH_RH_2', 'BH_RH_3',
    'BH_LH_1', 'BH_LH_2', 'BH_LH_3',
]


def rad_to_raw(angle_rad, offset_rad, direction):
    raw = CENTER_RAW + direction * (angle_rad + offset_rad) * RAD_TO_RAW
    return int(max(0, min(1023, round(raw))))


class DynamixelDriverNode(Node):
    def __init__(self):
        super().__init__('dynamixel_driver')

        self.declare_parameter('device',   '/dev/ttyUSB0')
        self.declare_parameter('baudrate', 1000000)

        device   = self.get_parameter('device').value
        baudrate = self.get_parameter('baudrate').value

        # Open port
        self._port   = PortHandler(device)
        self._packet = PacketHandler(PROTOCOL_VERSION)

        if not self._port.openPort():
            self.get_logger().fatal(f'Cannot open port: {device}')
            raise RuntimeError(f'Cannot open port: {device}')

        if not self._port.setBaudRate(baudrate):
            self.get_logger().fatal(f'Cannot set baudrate: {baudrate}')
            raise RuntimeError(f'Cannot set baudrate: {baudrate}')

        self.get_logger().info(f'Opened {device} at {baudrate} baud.')

        # SyncWrite group — same as your test script
        self._sync = GroupSyncWrite(
            self._port, self._packet,
            ADDR_GOAL_POSITION, LEN_GOAL_POSITION
        )

        # Enable torque on all 18 motors
        self._set_torque(True)

        # Subscribe to the same topic hexa_node publishes to
        self._sub = self.create_subscription(
            JointTrajectory,
            '/leg_trajectory_controller/joint_trajectory',
            self._callback,
            10
        )

        self.get_logger().info('Dynamixel driver ready.')

    def _callback(self, msg: JointTrajectory):
        if not msg.points:
            return

        # Map name → angle from the incoming message
        pos_map = dict(zip(msg.joint_names, msg.points[0].positions))

        # Load all 18 joints into SyncWrite
        for name in JOINT_ORDER:
            if name not in pos_map:
                self.get_logger().warn(f'Missing joint in message: {name}', throttle_duration_sec=5.0)
                self._sync.clearParam()
                return

            cfg = JOINT_CONFIG[name]
            raw = rad_to_raw(pos_map[name], cfg['offset'], cfg['dir'])
            ok  = self._sync.addParam(cfg['id'], [DXL_LOBYTE(raw), DXL_HIBYTE(raw)])
            if not ok:
                self.get_logger().error(f'addParam failed for {name} (ID {cfg["id"]})')
                self._sync.clearParam()
                return

        # Fire one SyncWrite packet — moves all 18 motors simultaneously
        result = self._sync.txPacket()
        if result != COMM_SUCCESS:
            self.get_logger().error(f'SyncWrite failed: {self._packet.getTxRxResult(result)}')

        self._sync.clearParam()

    def _set_torque(self, enable: bool):
        val = 1 if enable else 0
        self.get_logger().info(f'{"Enabling" if enable else "Disabling"} torque...')
        for name, cfg in JOINT_CONFIG.items():
            res, _ = self._packet.write1ByteTxRx(
                self._port, cfg['id'], ADDR_TORQUE_ENABLE, val
            )
            if res != COMM_SUCCESS:
                self.get_logger().warn(f'Torque set failed for {name} (ID {cfg["id"]})')

    def destroy_node(self):
        self.get_logger().info('Shutting down — disabling torque and closing port.')
        self._set_torque(False)
        self._port.closePort()
        super().destroy_node()


def main(args=None):
    rclpy.init(args=args)
    try:
        node = DynamixelDriverNode()
        rclpy.spin(node)
    except RuntimeError:
        pass
    except KeyboardInterrupt:
        pass
    finally:
        if rclpy.ok():
            rclpy.shutdown()


if __name__ == '__main__':
    main()

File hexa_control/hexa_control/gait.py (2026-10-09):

#!/usr/bin/env python3
import math
import numpy as np

# 6-Leg Order & Tripod Definitions
LEG_ORDER = ['FH_LH', 'FH_RH', 'MH_LH', 'MH_RH', 'BH_LH', 'BH_RH']
TRIPOD_A  = ['FH_LH', 'MH_RH', 'BH_LH']
TRIPOD_B  = ['FH_RH', 'MH_LH', 'BH_RH']


def _build_phase_matrix():
    n = len(LEG_ORDER)
    phi = np.zeros((n, n))
    for i, li in enumerate(LEG_ORDER):
        for j, lj in enumerate(LEG_ORDER):
            if (li in TRIPOD_A) != (lj in TRIPOD_A):
                phi[i, j] = math.pi
    return phi


PHASE_BIAS_MATRIX = _build_phase_matrix()


class CpgGait:
    """
    Real Coupled Asymmetric Hopf CPG with Duty Factor beta = 0.70 (70% Stance / 30% Swing).
    """

    def __init__(self, frequency=0.5, amplitude=0.08, normal_x=0.215, normal_z=-0.191, phase=0.0, duty_factor=0.70):
        # Kinematics and stance parameters
        self.frequency   = frequency
        self.amplitude   = amplitude
        self.normal_x    = normal_x
        self.normal_z    = normal_z
        self.phase       = phase
        self.duty_factor = duty_factor  # beta = 0.70 (70% Stance, 30% Swing)

        self.Tripod_A = TRIPOD_A
        self.Tripod_B = TRIPOD_B

        # Leg mounting angles around body (in radians)
        self.leg_mount_angles = {
            'FH_LH':  0.0,
            'MH_LH':  1.13,
            'BH_LH':  2.27,
            'BH_RH':  3.14,
            'MH_RH': -2.01,
            'FH_RH': -0.90,
        }

        # Nominal resting footprints
        self.default_foot_pos = {
            leg: np.array([self.normal_x, 0.0, self.normal_z])
            for leg in LEG_ORDER
        }

        # Hopf CPG Parameters
        self.mu    = 1.0                              # Target limit cycle radius squared (r = 1.0)
        self.alpha = 5.0                              # Convergence speed to limit cycle
        self.w     = 1.5                              # Inter-oscillator coupling strength
        self.omega = 2.0 * math.pi * self.frequency   # Base angular frequency

        # Asymmetric frequencies: Stance takes 70% of cycle, Swing takes 30%
        # omega_stance = omega / (2 * beta), omega_swing = omega / (2 * (1 - beta))
        self.omega_stance = self.omega / (2.0 * self.duty_factor)
        self.omega_swing  = self.omega / (2.0 * (1.0 - self.duty_factor))

        # Initialize states (Tripod A at phase 0, Tripod B at phase pi)
        n = len(LEG_ORDER)
        self._x = np.zeros(n)
        self._y = np.zeros(n)
        r0 = math.sqrt(self.mu)

        for i, leg in enumerate(LEG_ORDER):
            if leg in TRIPOD_A:
                self._x[i] = r0
                self._y[i] = 0.0
            else:
                self._x[i] = -r0
                self._y[i] = 0.0

    def _derivatives(self, x_state, y_state, speed_scale):
        """Computes dx/dt and dy/dt with asymmetric stance/swing frequency."""
        n = len(LEG_ORDER)
        dx = np.zeros(n)
        dy = np.zeros(n)

        for i in range(n):
            xi, yi = x_state[i], y_state[i]
            r2 = xi**2 + yi**2

            # Asymmetric frequency switching:
            # yi <= 0 -> Stance phase (slower rotation, 70% duration)
            # yi > 0  -> Swing phase  (faster rotation, 30% duration)
            if yi <= 0.0:
                omega_i = self.omega_stance * speed_scale
            else:
                omega_i = self.omega_swing * speed_scale

            # Hopf oscillator dynamics
            hopf_x = self.alpha * (self.mu - r2) * xi - omega_i * yi
            hopf_y = self.alpha * (self.mu - r2) * yi + omega_i * xi

            # Inter-limb phase coupling
            coupling_x = 0.0
            coupling_y = 0.0
            for j in range(n):
                if i == j:
                    continue
                phi_ij = PHASE_BIAS_MATRIX[i, j]
                xj, yj = x_state[j], y_state[j]
                cos_p = math.cos(phi_ij)
                sin_p = math.sin(phi_ij)

                xj_rot =  cos_p * xj - sin_p * yj
                yj_rot =  sin_p * xj + cos_p * yj

                coupling_x += (xj_rot - xi)
                coupling_y += (yj_rot - yi)

            dx[i] = hopf_x + self.w * coupling_x
            dy[i] = hopf_y + self.w * coupling_y

        return dx, dy

    def cpg_phase(self, dt, velocity):
        """RK4 numerical integration."""
        speed_scale = min(1.0, abs(velocity) / 0.02) if velocity > 0.001 else 0.0

        x, y = self._x.copy(), self._y.copy()

        k1x, k1y = self._derivatives(x,                    y,                    speed_scale)
        k2x, k2y = self._derivatives(x + 0.5 * dt * k1x, y + 0.5 * dt * k1y, speed_scale)
        k3x, k3y = self._derivatives(x + 0.5 * dt * k2x, y + 0.5 * dt * k2y, speed_scale)
        k4x, k4y = self._derivatives(x + dt * k3x,       y + dt * k3y,       speed_scale)

        self._x += (dt / 6.0) * (k1x + 2.0 * k2x + 2.0 * k3x + k4x)
        self._y += (dt / 6.0) * (k1y + 2.0 * k2y + 2.0 * k3y + k4y)

        self.phase = math.atan2(self._y[0], self._x[0]) % (2.0 * math.pi)
        return self.phase

    def foot_trajectory(self, leg, vx, vy, wz):
        i = LEG_ORDER.index(leg)
        xi, yi = self._x[i], self._y[i]
        
        # Normalized phase angle [0, 2*pi)
        leg_phase = math.atan2(yi, xi) % (2.0 * math.pi)

        # 1. Stride length in robot body frame
        shift_x_body = vx * (1.0 / self.frequency) * 0.5
        shift_y_body = vy * (1.0 / self.frequency) * 0.5

        # 2. Transform body stride into local leg frame
        alpha = self.leg_mount_angles[leg]
        shift_x_local =  math.cos(-alpha) * shift_x_body - math.sin(-alpha) * shift_y_body
        shift_y_local =  math.sin(-alpha) * shift_x_body + math.cos(-alpha) * shift_y_body

        shift_y_local += wz * 0.05

        base_pos = self.default_foot_pos[leg]

        # 3. 70% Stance vs 30% Swing foot trajectory
        # In this formulation:
        # leg_phase in [0, pi]     -> Stance (70% time because omega_stance is slower)
        # leg_phase in [pi, 2*pi]  -> Swing  (30% time because omega_swing is faster)
        if leg_phase < math.pi:
            # Stance: push ground backward
            progress = leg_phase / math.pi
            dx = -shift_x_local * (progress - 0.5)
            dy = -shift_y_local * (progress - 0.5)
            dz = 0.0
        else:
            # Swing: lift foot and advance forward quickly
            progress = (leg_phase - math.pi) / math.pi
            dx = shift_x_local * (progress - 0.5)
            dy = shift_y_local * (progress - 0.5)
            dz = self.amplitude * (math.sin(math.pi * progress) ** 0.8)

        return float(base_pos[0] + dx), float(base_pos[1] + dy), float(base_pos[2] + dz)

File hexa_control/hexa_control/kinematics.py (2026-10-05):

#!/usr/bin/env python3
import math

class Kinematics:
    def __init__(self, l1=0.051, l2=0.110, l3=0.148):
        self.l1 = l1
        self.l2 = l2
        self.l3 = l3

        self.femur_zero_angle = math.radians(-35.0)
        self.tibia_zero_angle = math.radians(-60.0)
        self.psi_zero = math.pi - abs(self.tibia_zero_angle - self.femur_zero_angle)

        self.limit_min = -2.094
        self.limit_max = 2.094

    def inverse_kinematics(self, x, y, z):

        theta1 = math.atan2(y, x)

        d = math.sqrt(x**2 + y**2) - self.l1
        D = math.sqrt(d**2 + z**2)

        cos_psi = (self.l2**2 + self.l3**2 - D**2) / (2.0 * self.l2 * self.l3)
        cos_psi = max(-1.0, min(1.0, cos_psi))
        psi = math.acos(cos_psi)

        theta3 = self.psi_zero - psi

        alpha1 = math.atan2(z, d)
        cos_alpha2 = (self.l2**2 + D**2 - self.l3**2) / (2.0 * self.l2 * D)
        cos_alpha2 = max(-1.0, min(1.0, cos_alpha2))
        alpha2 = math.acos(cos_alpha2)

        phi_femur = alpha1 + alpha2
        theta2 = phi_femur - self.femur_zero_angle

        theta1 = max(self.limit_min, min(self.limit_max, theta1))
        theta2 = max(self.limit_min, min(self.limit_max, theta2))
        theta3 = max(self.limit_min, min(self.limit_max, theta3))

        return theta1, theta2, theta3

    def forward_kinematics(self, theta1, theta2, theta3):
        phi_femur = theta2 + self.femur_zero_angle
        psi = self.psi_zero - theta3
        phi_tibia = phi_femur - (math.pi - psi)
        d = self.l2 * math.cos(phi_femur) + self.l3 * math.cos(phi_tibia)
        z = self.l2 * math.sin(phi_femur) + self.l3 * math.sin(phi_tibia)
        r_total = self.l1 + d
        x = r_total * math.cos(theta1)
        y = r_total * math.sin(theta1)

        return x, y, z

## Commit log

2026-10-05 Initial commit: hexapod ROS 2 packages + README
    - hexa_control: CPG Hopf-oscillator gait, 3-DOF IK/FK, main control node
    (50 Hz state machine), Dynamixel AX hardware driver, sim relay bridge
    - root_description: full URDF/xacro, STL meshes, Gazebo Fortress world,
    ros2_control config (JointTrajectoryController 100 Hz), launch files
    - README: project overview, architecture diagram, package docs, getting
    started guide, hardware specs, control reference, roadmap
    - .gitignore: excludes __pycache__, build/install/log artifacts
    [Dynamaxial.stl, Dynamaxial_cover_top.stl, base_link.stl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]
2026-10-05 changed no. of legs
2026-10-11 changed the leg
2026-10-14 added circuit
